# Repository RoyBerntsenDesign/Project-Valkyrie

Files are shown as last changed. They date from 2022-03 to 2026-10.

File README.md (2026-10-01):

# Valkyrie V2


Open-source, open-hardware DIY high-temperature CoreXY FFF platform.

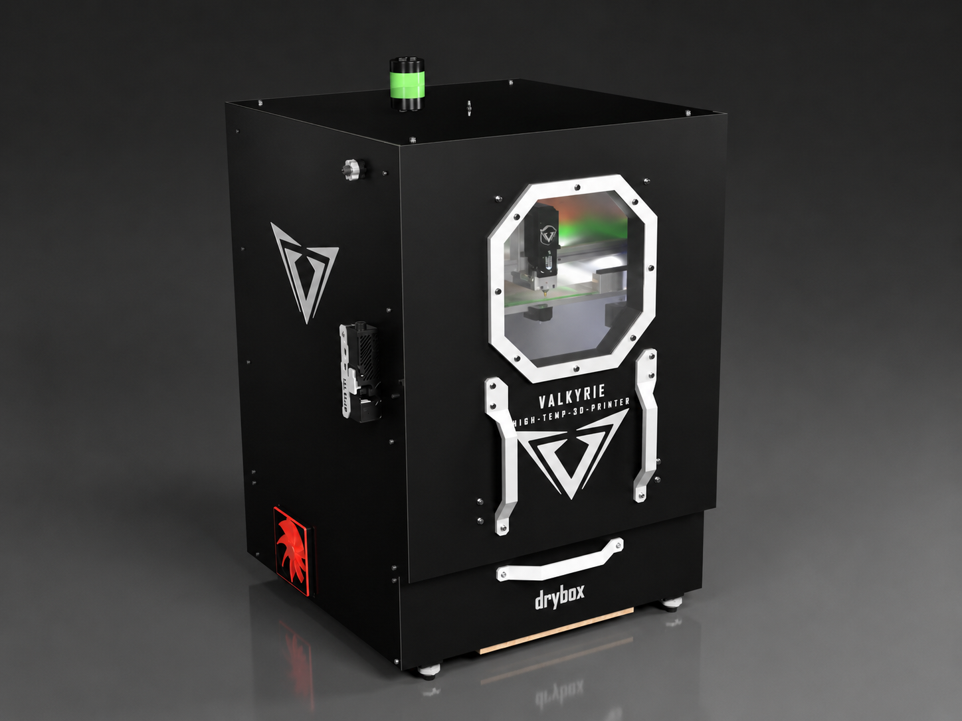
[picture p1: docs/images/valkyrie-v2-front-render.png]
Valkyrie V2 front render


Valkyrie V2 is a complete redesign of the Valkyrie high-temperature printer platform. The design focuses on structural rigidity, high-temperature operation, serviceability, thermal separation, and automated calibration.

The standard electrical configuration is 220-240 VAC. A 110-120 VAC configuration is possible only with configuration-specific heaters, power supplies, switching devices, wiring, connectors, and circuit protection.

## Project status

This repository contains Valkyrie V2.0.0-rc.1, the first release candidate for the Valkyrie V2 platform. Recommended operating values are separated from verified prototype results throughout the documentation. Materials and operating conditions that have not yet been validated are identified accordingly.

## Fusion 360 CAD Model

Explore the complete Valkyrie V2 assembly directly in Autodesk Fusion:

**➡️ [Open the Valkyrie V2 Fusion 360 Model](https://a360.co/4qquDOy)**

The online model includes the latest public design and allows you to inspect the complete assembly and individual components directly in your browser or Fusion 360.

## Main specifications

| System | Specification |
| --- | --- |
| Architecture | CoreXY |
| Build volume | 330 × 300 × 280 mm |
| Bed plate | 350 × 350 × 8 mm cast aluminium 5083 |
| Build sheet | 330 × 330 mm removable build sheet |
| XY motion | External dual-motor CoreXY with all-metal MGN12 linear rails |
| Z motion | Three independently driven belt-lift Z axes |
| XY motors | 2 × NEMA 17, 48 mm, 55 N·cm, 2.5 A, long-shaft |
| Z motors | 3 × NEMA 17, 40 mm, 45 N·cm, 2 A |
| Extruder | BTT V2X, 7:1 gearing, 73.5 N (7.5 kgf) rated extrusion force |
| Hotend | Custom water-cooled Valkyrie high-temperature hotend |
| Maximum nozzle temperature | Up to 500 °C |
| Maximum build-plate temperature | Up to 150 °C |
| Active chamber | Up to 110 °C verified |
| Chamber heater | 750 W PTC heater, configured as RRF Chamber 0 |
| Drybox heater | 300 W PTC heater, configured as RRF Chamber 1 |
| Chamber lighting | 3 × 350 mm, 24 V LED strips |
| Controller | Duet 3 6HC |
| Firmware | RepRapFirmware with Duet Web Control |
| Standard input | 220-240 VAC |
| Optional input | 110-120 VAC with configuration-specific components |

## Recommended and verified performance

| Performance | Recommended | Verified |
| --- | ---: | ---: |
| Print speed | Up to 500 mm/s | 1,000 mm/s |
| Acceleration | Up to 10,000 mm/s² | 10,000 mm/s² |
| Volumetric flow rate | Material-dependent | 45 mm³/s |
| Chamber temperature | Up to 110 °C | 110 °C sustained for 60 min |
| Drybox temperature | Up to 80 °C | 80 °C |
| Maximum travel speed | Up to 500 mm/s | 1,000 mm/s |
| Chamber heat-up | — | 30 min to 100 °C from 25 °C ambient |

Recommended values are intended as practical operating limits for the Valkyrie V2 reference configuration. Actual print settings depend on material, nozzle size, layer height, toolhead configuration, cooling, firmware tuning, and operating temperature.

Verified values represent results demonstrated on the Valkyrie V2 reference machine and should not be interpreted as required operating settings for every build.

## Design overview

### Frame and enclosure

- Aluminium extrusion frame assembled with M6 blind joints.
- Relocated upper rear extrusion for improved chamber sealing, panel installation, cable routing, and service access.
- Additional centre-rear Z extrusion for stiffness and support.
- Vertically lifting overhead door that does not require outward swing clearance.
- Reinforced door brackets with 625ZZ bearings, shoulder bolts, and linked side mechanisms.
- Primary electronics, motors, radiator, pump, and part-cooling blower positioned outside the heated chamber where practical.

### Motion system

- External 2.5 A CoreXY motors with long shafts and upper shaft supports.
- 16T GT2 drive pulleys for increased torque and nominal motion resolution.
- F606ZZ flanged CoreXY idlers.
- High-temperature all-metal MGN12 linear rails.
- Three independent belt-driven Z axes with 5:1 reduction and automatic Z alignment.

### Build platform and calibration

- Cast aluminium 5083 bed plate.
- Three-point Maxwell kinematic mounting system using 10 mm bearing balls.
- Integrated SmCo magnets and locating pins for repeatable build-sheet positioning.
- Bed-mounted nozzle and Z-offset reference sensor.
- Automatic three-point Z alignment, mesh-bed compensation, nozzle-height measurement, and nozzle brushing.

### Toolhead and thermal management

- Water-cooled BTT V2X extruder motor and custom Valkyrie hotend.
- Closed-loop cooling system using a P67D pump, reservoir, and external 120 mm radiator.
- 750 W PTC chamber heater with a 120 CFM recirculation fan.
- Heated bed provides a secondary chamber heat source.
- Independent thermal switch and firmware-configured heater protection.
- External ROBO blower recirculates heated chamber air for part cooling through a CPAP hose and toolhead duct.

### Material management

- Integrated heated filament drybox operating up to 80 °C.
- RepRapFirmware controls the drybox heater as Chamber 1.
- ESP32 monitoring of the DHT22 temperature/humidity sensor and filament load cell.
- Desiccant container and 625ZZ-bearing filament carousel.
- External filament buffer supporting automatic filament loading and unloading.

### Electronics and firmware

- Duet 3 6HC using all six onboard stepper-driver channels.
- Primary 24 V, 350 W power supply and secondary 12 V power supply.
- TS35 DIN-rail mains and 12 V distribution.
- Three solid-state relays for the bed, chamber, and drybox heaters.
- Three 350 mm, 24 V chamber LED strips: two vertical front strips pointing toward the rear and one top-front strip pointing toward the toolhead/build area.
- RepRapFirmware and Duet Web Control.
- Input shaping, pressure advance, automatic Z alignment, mesh compensation, thermal monitoring, and configurable print-start and print-end sequences.

## Firmware

Valkyrie V2 uses RepRapFirmware and Duet Web Control on the Duet 3 6HC.

The tested Valkyrie V2 firmware configuration is included in this repository:

[Open Valkyrie V2 Firmware Files](Firmware%20Files)

The supplied firmware package contains:

- `sys` – RepRapFirmware configuration, homing, system and safety files
- `macros` – Valkyrie-specific probing, calibration, nozzle and utility macros
- `filaments` – material-specific filament configuration, load and unload files

These files are configured for the Valkyrie V2 reference machine and should be used as the basis for the printer firmware setup.

### Firmware upgrades

For RepRapFirmware and Duet firmware upgrade procedures, follow the Valkyrie firmware upgrade guide:

[Valkyrie Firmware Upgrade Guide](https://docs.google.com/document/d/1ZG3JhbeEWcIs_WRdMjnoR0Aa20OJ4TtpdeJnv2xmSmU/edit?usp=sharing)

Back up the SD card before making firmware or configuration changes.

Machine-specific settings such as input shaping, probe offsets and filament profiles may require adjustment on individual builds.

## Material validation

Validated on the current prototype:

- PLA
- PETG
- ABS
- ASA
- PA and PA-CF
- PC, PC-CF, and PC blend CF
- PPS, PPS-CF, and PPS-GF

Still to be verified:

- PSU
- PPSU
- PEI (Ultem)
- PEKK

## Documentation

- [Valkyrie V2 Technical Overview v1.1](docs/Valkyrie_V2_Technical_Overview_v1.1.pdf)
- [Valkyrie V2.0.0-rc.1 release notes](RELEASE_NOTES.md)

The technical overview describes the machine architecture and prototype configuration. It is not an assembly manual or electrical wiring guide.

## Support

For build assistance, troubleshooting, and questions about Valkyrie V2, please join the official Project Valkyrie Discord server:

[**Get support on Discord**](https://discord.gg/mWARcpt7NQ)

## Safety

Valkyrie V2 uses mains-voltage heaters, high current, high temperatures, moving machinery, and liquid cooling. Mains-voltage components, wiring, connectors, protective earth, fusing, insulation, and clearances must be selected and installed for the configured input voltage by a qualified person in accordance with applicable regulations and manufacturer ratings.

Do not use the project documentation as a substitute for electrical design verification, risk assessment, or compliance testing.

## Credits

### Project lead

**Roy Berntsen** - Project lead, primary mechanical designer, and system integrator.

### Contributors

- **Mark Bridgewater** - Design, electronics, firmware, testing, and documentation.
- **Chris Lombardi** - ESP32 firmware.

### Acknowledgements

- RepRapFirmware
- Duet Web Control
- Duet3D
- BIQU

## Licensing

Beginning with V2.0.0-rc.1, Valkyrie V2 is released as an open-source and open-hardware project.

- Hardware design files: **CERN-OHL-S-2.0**
- Valkyrie firmware, macros, and configuration: **GPL-3.0-or-later**
- Documentation and original project media: **CC-BY-4.0**

Earlier tagged releases remain under the licence terms under which they were originally published. Third-party materials remain subject to their respective licences.

See [License.md](License.md) and the full licence texts in [LICENSES](LICENSES).

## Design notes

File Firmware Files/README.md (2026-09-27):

# Valkyrie V2 – RepRapFirmware Files

These files contain the Valkyrie V2 RepRapFirmware configuration used on the reference machine.

The supplied `sys`, `macros` and `filaments` folders should be used as the basis for the Valkyrie V2 firmware setup.

## Included folders

- `sys`  
  Main RepRapFirmware configuration files, homing files, daemon logic, pause/resume, stop/cancel and other system files.

- `macros`  
  Valkyrie-specific macros for probing, nozzle handling, Z-offset calibration, chamber control and other printer functions.

- `filaments`  
  Material-specific filament configuration, load and unload files.

## Installation

1. Back up the existing SD card before making any changes.
2. Download the Valkyrie V2 firmware files from this repository.
3. Copy the supplied `sys`, `macros` and `filaments` folders to the Duet SD card.
4. Follow the Valkyrie firmware upgrade guide when updating RepRapFirmware or Duet firmware.
5. Restart the controller.
6. Verify the machine configuration before enabling heaters or motion.

## Firmware Upgrade Guide

For RepRapFirmware and Duet firmware upgrade procedures, use the Valkyrie firmware upgrade documentation:

[Valkyrie Firmware Upgrade Guide](https://docs.google.com/document/d/1ZG3JhbeEWcIs_WRdMjnoR0Aa20OJ4TtpdeJnv2xmSmU/edit?usp=sharing)

## Important

These files are configured specifically for the Valkyrie V2 hardware.

Before operating the machine, verify:

- motor directions
- axis limits
- sensorless homing behaviour
- heater and thermistor assignments
- fan assignments
- probe inputs
- Z-probe offsets
- mains-powered heater control
- chamber safety systems

## Input Shaping

The included input-shaping configuration was measured on the Valkyrie V2 reference machine.

Another build may have different resonance characteristics due to differences in:

- frame assembly
- belt tension
- toolhead mass
- component tolerances
- mounting
- modifications

Input shaping should therefore be measured and tuned on each machine where possible.

## Filament Profiles

The supplied filament profiles are based on the materials and settings used on the Valkyrie V2 reference machine.

Temperatures, purge lengths, drybox temperatures and other material-specific settings may need adjustment for different filament brands and formulations.

## Safety

Valkyrie is a DIY high-temperature 3D printer and includes mains-voltage heaters.

Make sure all wiring, grounding, fusing, thermal protection and heater configuration are checked before operating the machine.

Do not rely on firmware as the only safety system.

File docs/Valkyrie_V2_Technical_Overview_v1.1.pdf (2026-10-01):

# Valkyrie V2 Technical Overview

## Open-Source / Open-Hardware DIY High-Temperature CoreXY Platform

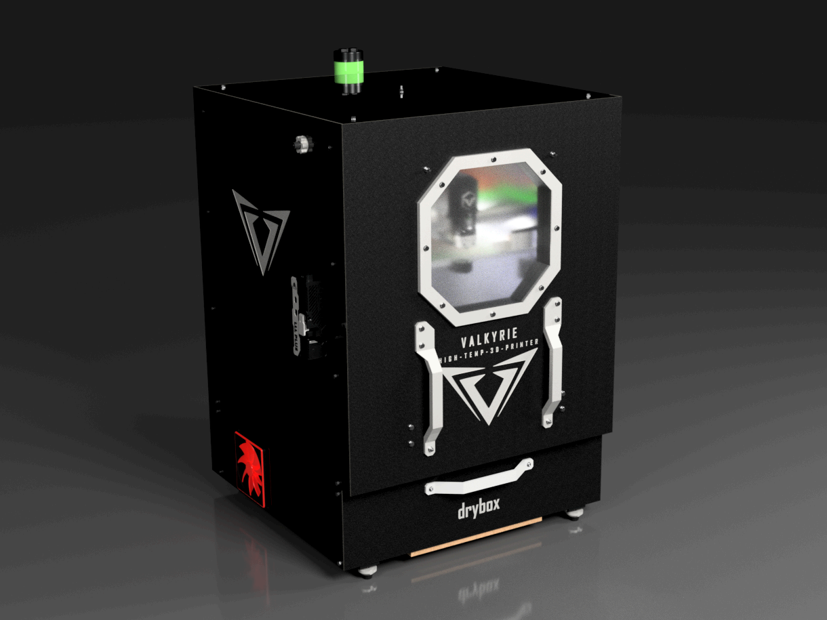
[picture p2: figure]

Designed and developed by Roy Berntsen Document version 1.1
October 2026

## Table of Contents INTRODUCTION

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
cific

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
cific

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
rial C

o

m

p

a

tibilit

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
alib

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
olin

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
olin

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
Fila

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
ol | 1
| 3
Fila

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
m | 1
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
ol | 1
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
ol | 1
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
m | 1
| 5
M

ain

s In

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
n | 1
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
al In

t

e

rf

a

c

e | 1
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
olin

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
g | 1
| 6
E

x

t

e

r

n

al Ele

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
N | 1
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
r In

t

e

rf

a

c

e | 1
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
ol | 1
| 7
T

h

e

r

m

al M

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
t | 1
| 7
C

alib

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
s | 1
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
g | 1
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
d | 1
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
s | 1
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
## INTRODUCTION

The Valkyrie V2 is a next-generation, open-source and open-hardware DIY high-temperature CoreXY FFF platform engineered for reliable processing of advanced engineering polymers and fibre-reinforced composites. Every major subsystem has been redesigned to increase structural rigidity, improve motion precision, enhance thermal capability, and simplify servicing while maintaining an open and modular architecture.

This document provides a technical overview of the major design changes and new features introduced in the Valkyrie V2 platform.

Safety Notice
This document is a technical overview, not a wiring or construction guide. Mains-voltage components, wiring, connectors, protective earth, fusing, insulation, and clearances must be selected and installed for the configured input voltage by a qualified person in accordance with applicable regulations and manufacturer ratings.

## SPECIFICATIONS

System Specifications

Specification | Valkyrie V2
Printer Architecture | CoreXY
Build Volume | 330 × 300 × 280 mm
Frame Construction | Aluminium extrusion frame
XY Motion System | CoreXY with external NEMA 17 stepper motors
XY Motors | 2 × NEMA 17, 48 mm, 55 N·cm, 2.5 A, long-shaft
Z Motion System | Three independently driven belt-lift Z axes
Z Motors | 3 × NEMA 17, 40 mm, 45 N·cm, 2 A
XY Positioning Resolution | 10 µm/step
Z Positioning Resolution | 2.5 µm/step
Linear Rails | High-temperature all-metal MGN12
Extruder | BTT V2X, 7:1 gearing
Extrusion Force | 73.5 N (7.5 kgf)
Hotend | Custom water-cooled Valkyrie hotend
Maximum Nozzle Temperature | Up to 500 °C

Maximum Build Plate Temperature | Up to 150 °C
Active Chamber Temperature | Up to 110 °C verified
Chamber Heating | 750 W PTC heater (RRF Chamber 0)
Chamber Lighting | 3 × 350 mm, 24 V LED strips
Bed Plate | 350 × 350 × 8 mm Cast Aluminium Al 5083
Bed Mounting | 3-point Maxwell kinematic system with 10 mm bearing balls
Build Plate Retention | Integrated SmCo magnets
Calibration | Automatic tool probe, Z sensor, mesh bed levelling
Part Cooling | Recirculated chamber-air CPAP system
Toolhead Cooling | Closed-loop water cooling
Water Cooling | 12 V P67D pump, reservoir, and 120 mm radiator
Filament Storage | Integrated heated drybox
Drybox Heating | 300 W PTC heater (RRF Chamber 1)
Drybox Control | RRF Chamber 1 heater control with ESP32/DHT22 monitoring
Filament Monitoring | Integrated load cell with remaining filament weight
Filament Feeding | External filament buffer
Control Electronics | Duet 3 6HC
Firmware | RepRapFirmware
User Interface | Duet Web Control (DWC)
Standard Input Voltage | 220–240 VAC
Optional Input Voltage | 110–120 VAC with configuration-specific electrical components
Mains Protection | 10 A fuse for the standard 220–240 VAC configuration
Machine Weight | ~50 kg

The Valkyrie V2 is designed around a standard 220–240 VAC electrical configuration. An optional 110–120 VAC configuration may be built using appropriately rated heaters, power supplies, switching devices, wiring, connectors, and circuit protection

Performance Specifications

Performance | Recommended | Verified
Print Speed | Up to 500 mm/s | 1,000 mm/s
Acceleration | Up to 10,000 mm/s² | 10,000 mm/s²
Volumetric Flow Rate | Material-dependent | 45 mm³/s
Maximum Travel Speed | Up to 500 mm/s | 1,000 mm/s
Chamber Heat-Up Time | — | 30 min to 100 °C (from 25 °C ambient)
Chamber Temperature | Up to 110 °C | 110 °C for 60 min
Drybox Temperature Range | Up to 80 °C | 80 °C

Material Compatibility

Material | Status
PLA | ✓
PETG | ✓
ABS | ✓
ASA | ✓
PA/PA-CF | ✓
PC/PC-CF/PC Blend CF | ✓
PPS/PPS-CF/GF | ✓
PSU | To be verified
PPSU | To be verified
PEI (Ultem) | To be verified
PEKK | To be verified

✓ = Verified on the current prototype. “To be verified” indicates materials that have not yet been validated The Valkyrie V2 is designed to process engineering-grade thermoplastics and fibre-reinforced composites.

## 1.MACHINE PLATFORM

FRAME

- Increased frame rigidity with M6 blind joints while simplifying the assembly process
- Improved chamber sealing and cable routing by relocating the upper rear 2020 X profile
- Added a center rear 2020 Z extrusion to improve structural stiffness and support
- Redesigned the top frame structure to enable top-mounted linear rails for easier installation and servicing

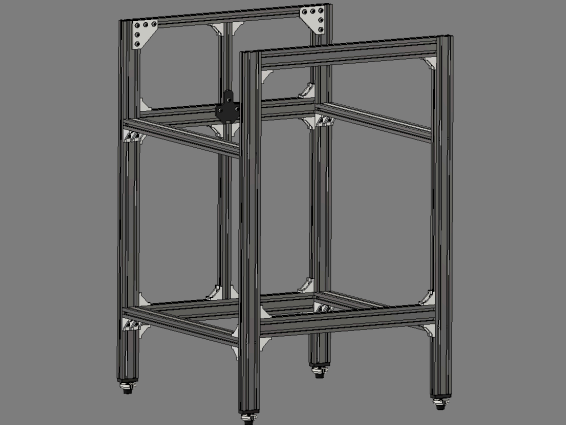
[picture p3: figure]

Figure 1 — Valkyrie V2 frame.

ENCLOSURE

- Redesigned enclosure architecture for improved chamber sealing and reduced heat loss during high-temperature operation
- Relocated upper rear 2020 X profile to simplify panel installation, improve sealing, and provide cleaner cable routing
- Improved separation between the heated build chamber and temperature-sensitive electronics and cooling components
- Service-oriented panel arrangement providing access to motion, wiring, and thermal-management components
- External mounting of the CoreXY motors, Z motors, water-cooling radiator, pump, and part cooling blower fan to reduce exposure to elevated chamber temperatures
- Integrated routing interfaces for toolhead wiring, water-cooling hoses, CPAP ducting, and filament feeding
- Redesigned overhead-lifting door system that opens vertically instead of swinging outward, reducing the required clearance in front of the machine
- Upgraded door hinge and linkage system featuring:
- New reinforced mounting brackets
- 625ZZ bearings and shoulder bolts at the arm and bracket pivot points for smoother movement and reduced play
- Improved mechanical linkage between both sides for synchronized door movement and more consistent alignment
(a) Closed door | (b) Open door

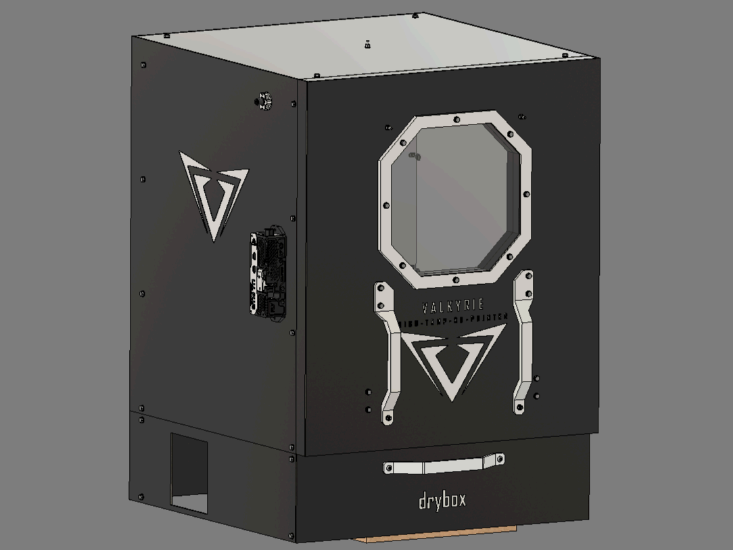
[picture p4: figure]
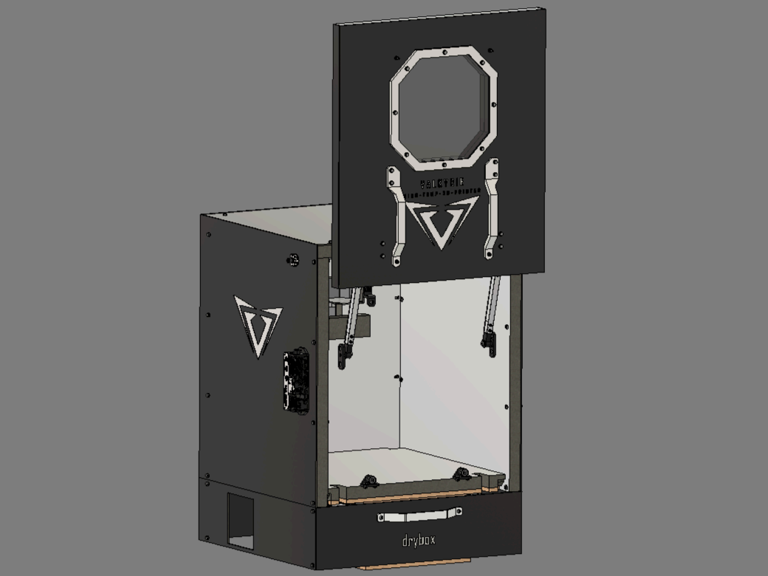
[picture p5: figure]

Figure 2 - Valkyrie V2 overhead door in the closed and fully raised positions. The vertically lifting mechanism provides unobstructed access to the build chamber without requiring additional clearance in front of the machine.

## 2.MOTION SYSTEM

CoreXY Motion System

- New external 2.5 A NEMA 17 long-shaft stepper motors with top-supported shafts for improved drive stiffness:
- Reduced shaft deflection for improved motion consistency and repeatability
- Improved pulley alignment and belt stability
- Increased belt tension capability for a stiffer CoreXY drive system
- Increased acceleration capability and torque margin
- Improved reliability during high-temperature operation
- Reduced CoreXY drive pulleys from 20T to 16T GT2 for increased positioning resolution at 10 µm/step and higher torque
- Upgraded all GT2 idlers to large diameter F606ZZ flanged bearings for reduced friction, improved belt guidance, less belt stress, and increased long-term reliability
- Upgraded AB motion system to all-metal high-temperature MGN12 linear rails for improved rigidity and reliability in elevated chamber temperatures
- Redesigned AB and Y motion components for improved rigidity, belt alignment, and serviceability

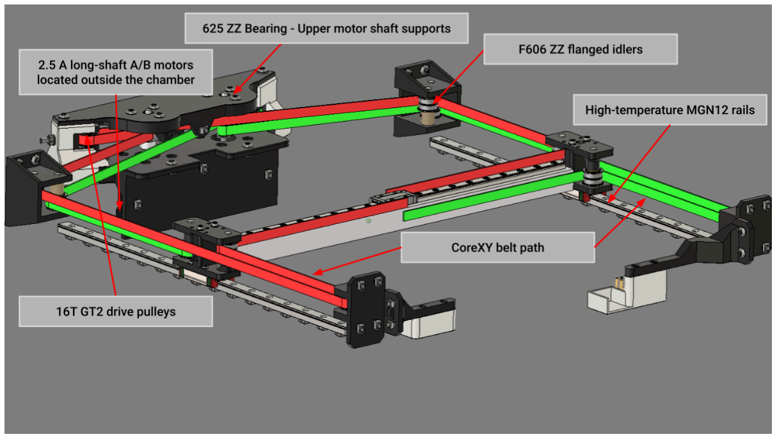
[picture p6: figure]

Figure 3 — Valkyrie V2 CoreXY motion system showing the external long-shaft A/B motors, upper shaft supports, 16T drive pulleys, F606ZZ idlers, and high-temperature MGN12 linear rails.

Z Motion System

- Redesigned Z carriers for increased rigidity, improved belt clamping, and ease of servicing
- New top-mounted Z idler brackets for maximum toolhead travel and optimized belt routing
- Increased Z drive reduction from 4:1 to 5:1 using 16T GT2 pulleys for higher positioning resolution at 2.5 µm/step and increased torque
- Upgraded Z belt idlers to GT2 pulleys on 625ZZ bearing shafts for improved belt guidance and reduced friction
- High-temperature all-metal MGN12 linear rails for improved reliability in elevated chamber temperatures

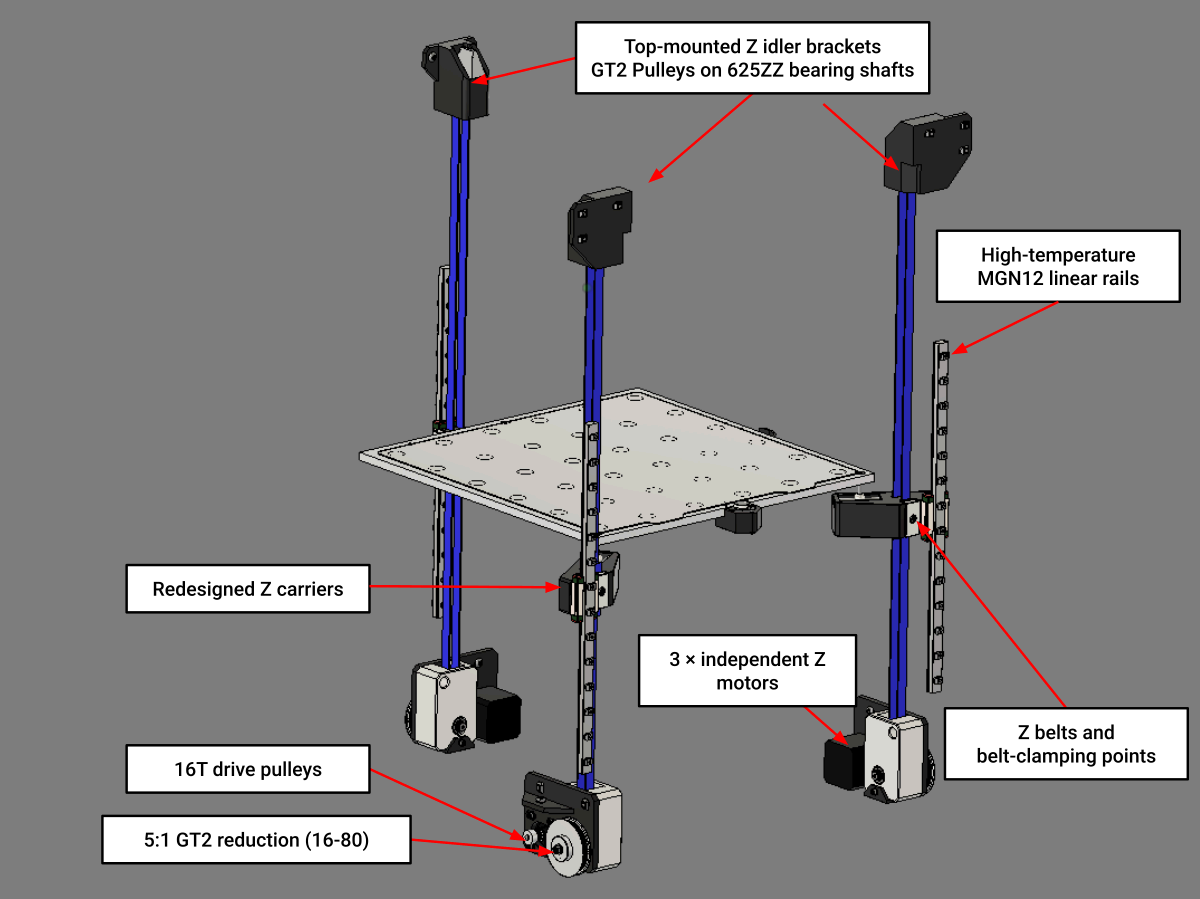
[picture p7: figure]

Figure 4 — Three-axis Z motion system featuring independent NEMA 17 motors, 5:1 GT2 reduction, top-mounted idlers, redesigned Z carriers, and high-temperature MGN12 linear rails.

## 3.BUILD PLATFORM

Bed System

- Integrated SmCo magnets for secure build plate retention and improved high-temperature stability
- Redesigned bed wiring with improved strain relief and integrated thermal fuse for increased electrical safety
- Added locating pins for repeatable build plate positioning and alignment
- 3-point independent Maxwell kinematic bed system using 10 mm bearing balls for high stability and repeatable bed positioning

Calibration System

- New Valkyrie tool probe system for automatic Z-offset measurement and nozzle height calibration
- Bed-mounted nozzle/Z-offset sensor provides a fixed reference for automatic nozzle-height measurement and Z-offset calibration
- Improved calibration repeatability for consistent first-layer performance

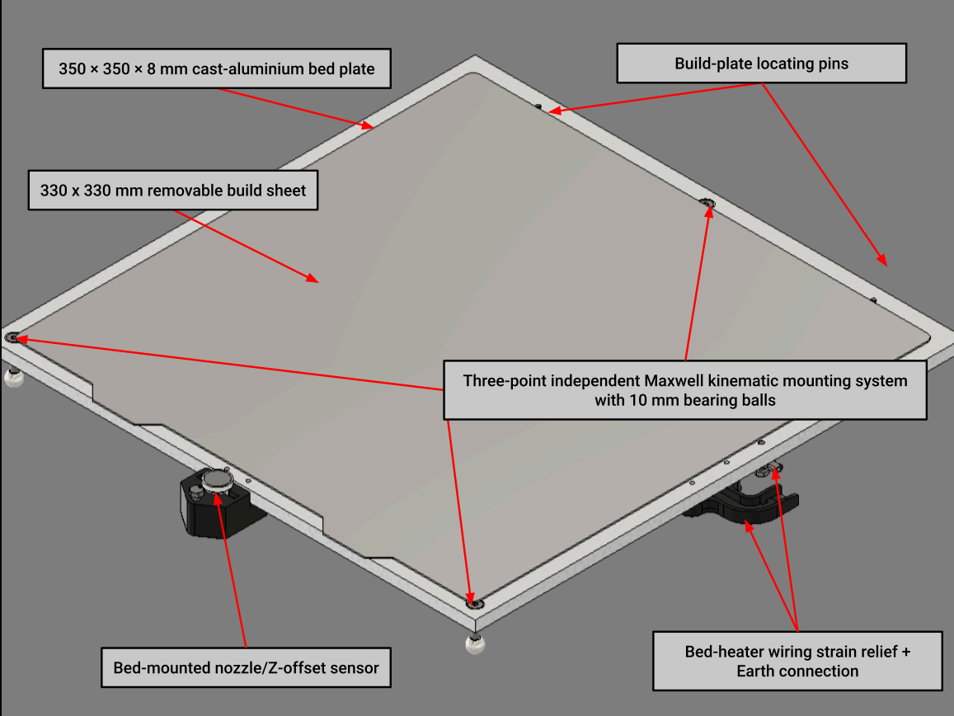
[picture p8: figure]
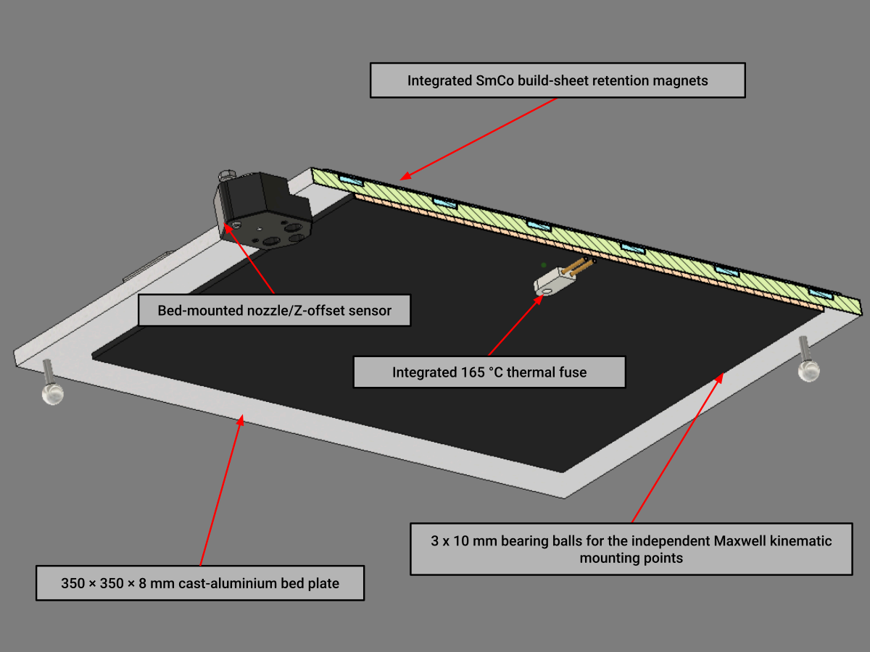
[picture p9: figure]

(a) Top view | (b) Underside view

Figure 5 — Valkyrie V2 build platform: (a) 330 × 330 mm removable build sheet, cast-aluminium bed plate, SmCo magnetic retention, locating pins, and bed-mounted nozzle/Z-offset sensor; (b) three-point Maxwell kinematic mounting system, heater wiring, strain relief, and thermal fuse.

## 4.TOOLHEAD PLATFORM

- New water-cooled BTT V2X high-torque extruder featuring 7:1 gearing and 73.5 N (7.5 kgf) extrusion force for reliable high-force extrusion and high-flow material processing
- Custom water-cooled high-temperature hotend developed specifically for the Valkyrie V2 toolhead, featuring an integrated toolplate mounting interface for improved rigidity, alignment, and serviceability
- Redesigned integrated toolhead cable management featuring:
- Top-mounted cable chimney routing through the toolhead cover
- Integrated side cable channel for cleaner cable routing and improved protection
- Redesigned Z probe system with SmCo magnets for improved thermal stability and repeatability
- New magnetic Z probe docking station with SmCo magnets for secure probe retention and consistent positioning
- New nozzle brushing station for improved nozzle maintenance and print reliability

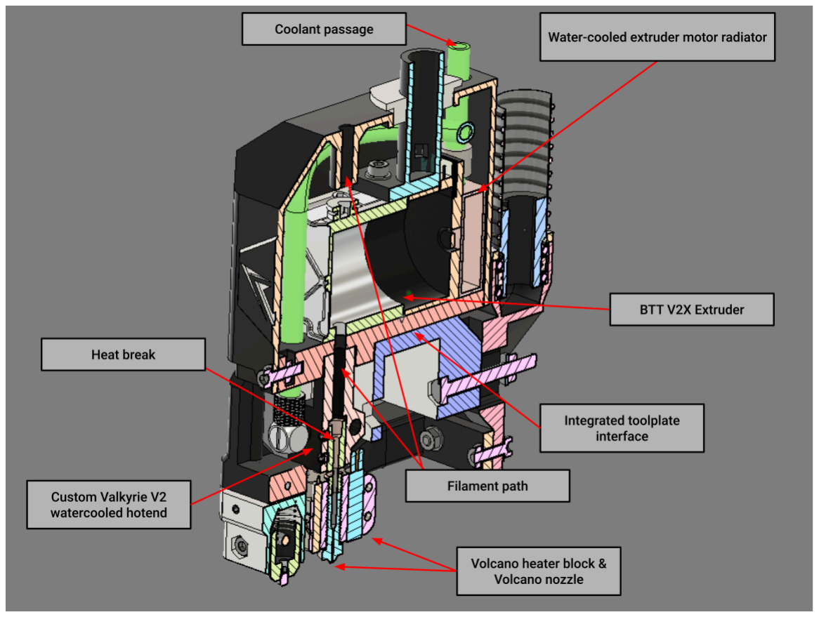
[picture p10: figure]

Figure 6 — Section view of the Valkyrie V2 toolhead showing the filament path, extruder drive, integrated mounting interface, and water-cooled high-temperature hotend assembly.

## 5.THERMAL MANAGEMENT

Water Cooling System

- Closed-loop water-cooling system using a 12 V P67D pump with water reservoir
- Dedicated cooling circuit for the extruder motor and hotend
- Integrated reservoir with fill and bleed ports for simplified coolant filling and air removal
- 120 mm radiator mounted outside the heated chamber for efficient heat rejection
- PWM-controlled radiator fan
- Cooling system isolated from the heated chamber environment

Chamber Heating System

- Dedicated 220 V, 750 W PTC chamber heater positioned centrally at the rear of the build chamber
- 220 V, 750 W heated bed provides an additional secondary heat source during chamber heating
- High-flow 120 CFM, 12 V, 92 × 92 × 38 mm circulation fan distributes heated air throughout the chamber
- Fully recirculated airflow maintains a uniform chamber temperature without introducing cooler external air
- Temperature sensor positioned at nozzle level for representative chamber-temperature measurement
- Controlled chamber operation verified up to 110 °C for processing high-temperature engineering polymers; sustained operation verified at 110 °C for 60 min
- Integrated thermal switch provides independent hardware over-temperature protection
- Firmware-configured temperature limits and automatic heater shutoff provide additional thermal safety

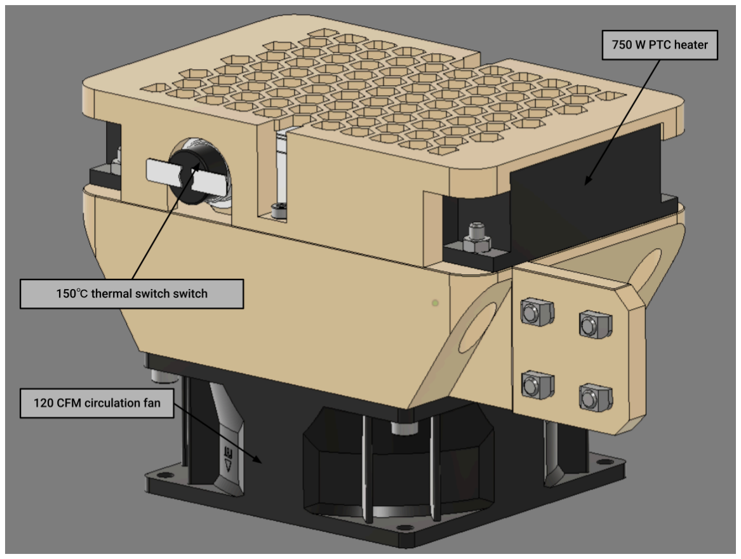
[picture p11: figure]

Figure 7 — Chamber-heating assembly showing the 750 W PTC heater, 120 CFM chamber-circulation fan, and independent 150 °C thermal safety switch.

Part Cooling System

- High-flow part-cooling system using an external 12 V ROBO CPAP fan
- Recirculates heated chamber air instead of introducing cooler external air, minimizing thermal shock during high-temperature printing
- Directs controlled airflow through the toolhead chimney and duct system onto the printed part
- Improves overhang and bridging performance when processing high-temperature engineering polymers
- Bearing-supported CPAP hose swivel allows free hose rotation and reduces mechanical load on the moving toolhead
- Adjustable fan control enables part-cooling airflow to be matched to the material and printing conditions

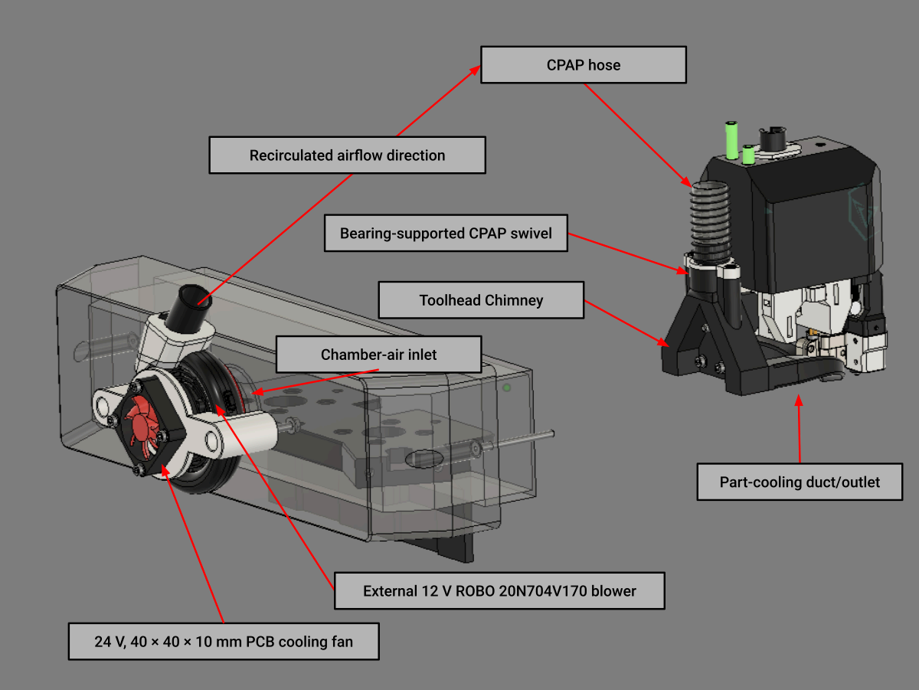
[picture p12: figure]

Figure 8 — Valkyrie V2 recirculated-air part-cooling system showing the chamber-air inlet, external ROBO blower, dedicated control-PCB cooling fan, CPAP hose, bearing-supported swivel, and toolhead duct directing heated chamber air onto the printed part.

## 6.MATERIAL MANAGEMENT

Filament Drybox

- Integrated enclosed filament drybox for moisture-sensitive engineering materials
- Dedicated 300 W PTC heater with independent temperature control
- Integrated desiccant container for passive moisture absorption and low-humidity filament storage
- Integrated humidity sensor for continuous drybox monitoring
- Integrated load cell for continuous filament-weight measurement
- Bearing-supported filament carousel using 625ZZ bearings for low-friction rotation and reliable filament feeding
- Drybox operating temperature up to 80 °C

Drybox Monitoring and Control

- RepRapFirmware directly controls the 300 W drybox PTC heater through a dedicated solid-state relay
- The drybox heater is configured in Duet Web Control as Chamber 1
- Drybox temperature setpoint, heater status, and temperature regulation are managed through DWC
- ESP32 monitoring reads the DHT22 temperature/humidity sensor and load cell
- The load cell provides continuous measurement of remaining filament weight
- The ESP32 operates as a monitoring system and does not switch or regulate the drybox PTC heater

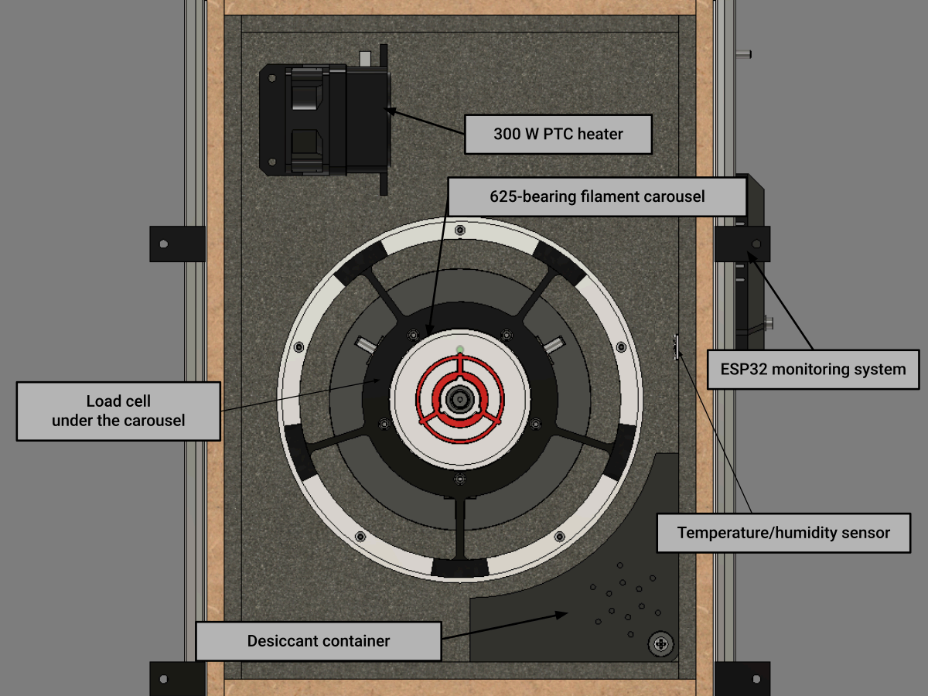
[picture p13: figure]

Figure 9 — Integrated filament drybox showing the heated and monitored storage system, desiccant container, load cell, and bearing-supported filament carousel

Filament Feed System

- External filament buffer positioned between the drybox and toolhead
- Isolates the extruder from spool inertia and drybox feed resistance
- Maintains consistent filament delivery during high-speed printing
- Supports automatic filament loading and unloading directly through the buffer
- Provides controlled filament storage and movement during loading, printing, and unloading operations

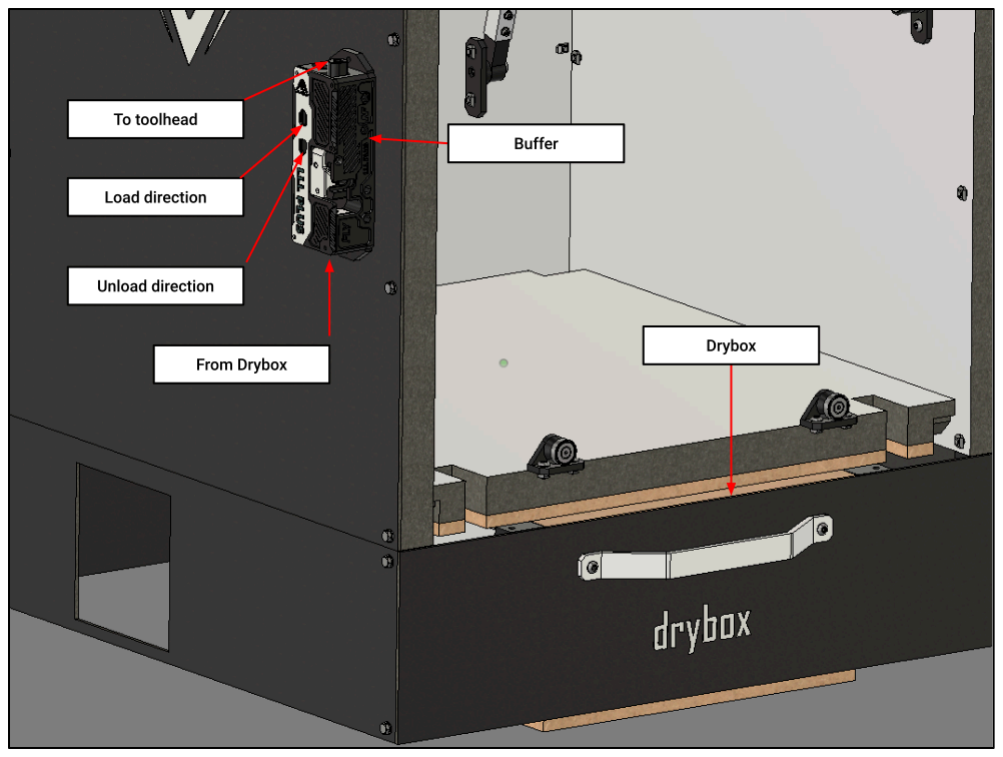
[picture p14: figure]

Figure 10 — External filament buffer providing automatic filament loading and unloading while isolating the toolhead extruder from spool inertia and drybox feed resistance.

## 7. ELECTRONICS & CONTROL SYSTEM

Main Control

- Duet 3 6HC main controller with six integrated stepper-driver channels
- No Duet expansion boards or CAN-connected toolhead electronics
- Controller mounted on the rear panel outside the heated build chamber for improved thermal reliability and service access
- All primary control and power-distribution electronics are located outside the heated chamber
- GX20 panel connectors positioned immediately outside the chamber provide the toolhead electrical interface

Motor Control

- Two independently driven CoreXY A/B motors:
- NEMA 17
- 48 mm body length
- 55 N·cm holding torque
- 2.5 A rated current
- Long shafts with upper support
- Three independently driven Z motors:
- NEMA 17
- 40 mm body length
- 45 N·cm holding torque
- 2 A rated current
- One driver channel controls the BTT V2X extruder motor
- Independent control of the three Z motors enables automatic build-platform alignment
- All six onboard Duet 3 6HC stepper-driver channels are utilized

Power System

- Primary 24 V, 350 W power supply for the controller, motion system, chamber lighting, and other 24 V components
- Secondary 12 V power supply for pumps, fans, and auxiliary 12 V components
- TS35 DIN-rail-mounted mains and 12 V distribution for organized and serviceable wiring
- Three solid-state relays with 24 V DC control inputs switch the following 220 V AC heating loads:
- 750 W build-plate heater
- 750 W chamber PTC heater
- 300 W drybox PTC heater

Mains Input and Protection

- Main IEC connector provides the external AC power connection
- Dedicated main power switch
- 15 A panel-mounted fuse holder fitted with a 10 A mains fuse

Chamber Electrical Interface

- High-temperature HDC connectors provide centralized, serviceable connections between the electronics system and heated chamber
- One 6-pin HDC connector supplies the 750 W chamber PTC heater
- One 6-pin HDC connector supplies the 4-pin 120 CFM chamber circulation fan
- One 10-pin HDC connector carries connections for:
- Build-plate heater
- Bed thermistor
- Z-offset/nozzle sensor
- Protective earth
- Centralized chamber connectors simplify installation, servicing, and component replacement

Electronics and Component Cooling

- 12 V, 120 × 120 × 25 mm fan for the water-cooling radiator
- 12 V ROBO 20N704V170 blower for recirculated-air part cooling
- 12 V, 60 × 60 × 25 mm fan for drybox-heater air circulation
- 12 V, 92 × 92 × 38 mm, 120 CFM fan for chamber-heater air circulation
- 24 V, 40 × 40 × 10 mm fan for Duet 3 6HC cooling
- 24 V, 40 × 40 × 10 mm fan for ROBO-fan control-PCB cooling

Chamber Lighting

- Three internal 24 V LED strips, each 350 mm long, provide illumination of the build chamber
- Two vertically mounted LED strips are installed on the front Z profiles and directed toward the rear of the chamber
- One LED strip is mounted at the top front of the chamber and directed toward the toolhead and build area
- Combined front and overhead illumination improves visibility of the toolhead, printed part, and internal chamber components

External Electronics Architecture

- Active electronics are positioned outside the heated build chamber wherever possible. The water-cooled toolhead extruder motor and the chamber circulation fan are the only active electromechanical components operating inside the chamber.
- External component placement reduces thermal exposure and improves reliability, accessibility, and serviceability

## 8. FIRMWARE & AUTOMATION

Firmware and User Interface

- RepRapFirmware (RRF) provides motion control, thermal management, calibration, safety monitoring, and printer automation
- Duet Web Control (DWC) provides the primary browser-based interface for printer operation, monitoring, file management, and configuration
- Printer configuration files and macros are stored locally on the Duet 3 6HC controller

Motion Control

- Input shaping reduces vibration and motion-related surface artifacts
- Pressure advance compensates for extrusion-system pressure changes during acceleration and deceleration
- Automated axis-homing routines establish repeatable machine coordinates
- Independent control of three Z motors enables automatic build-platform alignment
- Configurable speed, acceleration, current, and motion limits for each axis

Thermal Management

- Closed-loop temperature regulation for the hotend, build plate, and heated chamber
- RepRapFirmware independently regulates the drybox PTC heater as Chamber 1, with its temperature setpoint and operating status accessible through Duet Web Control
- Print start heats the chamber and bed first, waits for the configured minimum chamber temperature, then heats the hotend to reduce unnecessary high-temperature dwell
- Chamber, drybox, and water-pump tachometer monitoring supplements heater limits and sensor-fault handling; confirmed cooling faults trigger automatic heater shutdown
- Temperature-sensor faults automatically disable the affected heater

Calibration

- Automatic three-point Z alignment using the independently driven Z motors
- Automatic mesh bed levelling compensates for build-surface variation
- Valkyrie tool-probe system measures nozzle height and Z offset
- Automated nozzle-probing sequence provides repeatable first-layer calibration
- Nozzle-brushing routine cleans the nozzle before probing and printing

Safety

- Thermal-runaway and cooling-system monitoring for firmware-controlled heaters
- Configurable minimum- and maximum-temperature limits
- Automatic heater shutdown following sensor faults, heating errors, exceeded limits, or confirmed fan/pump cooling faults
- Independent thermal switches provide hardware-level over-temperature protection
- Build-plate heater wiring includes an integrated thermal fuse
- Mains fuse protects the printer’s primary electrical input

Automation Features

- Automated machine homing and three-point bed alignment
- Automatic Z-offset measurement and mesh-bed calibration
- Automatic nozzle-brushing sequence
- Automated filament loading and unloading through the external filament buffer
- Print-start sequence heats the chamber and bed first, waits for the configured minimum chamber temperature, then heats the hotend before homing and calibration
- Configurable print-end sequence for heater shutdown, toolhead parking, and filament management

## Credits and Licensing

Project Lead

Roy Berntsen
Project lead, primary mechanical designer and system integrator

Contributors

- Mark Bridgewater — Design, electronics, firmware, testing and documentation
- Chris Lombardi — ESP32 firmware

Acknowledgements
- RepRapFirmware and Duet Web Control
- Duet3D and BIQU

Licensing

Beginning with Valkyrie V2.0.0-rc.1, Project Valkyrie is released as an open-source and open-hardware project. Hardware design files are licensed under CERN-OHL-S-2.0, original Valkyrie firmware and configuration under GPL-3.0-or-later, and original documentation and project media under CC-BY-4.0. Earlier tagged releases remain under their original licence terms. Third-party materials remain subject to their respective licences.

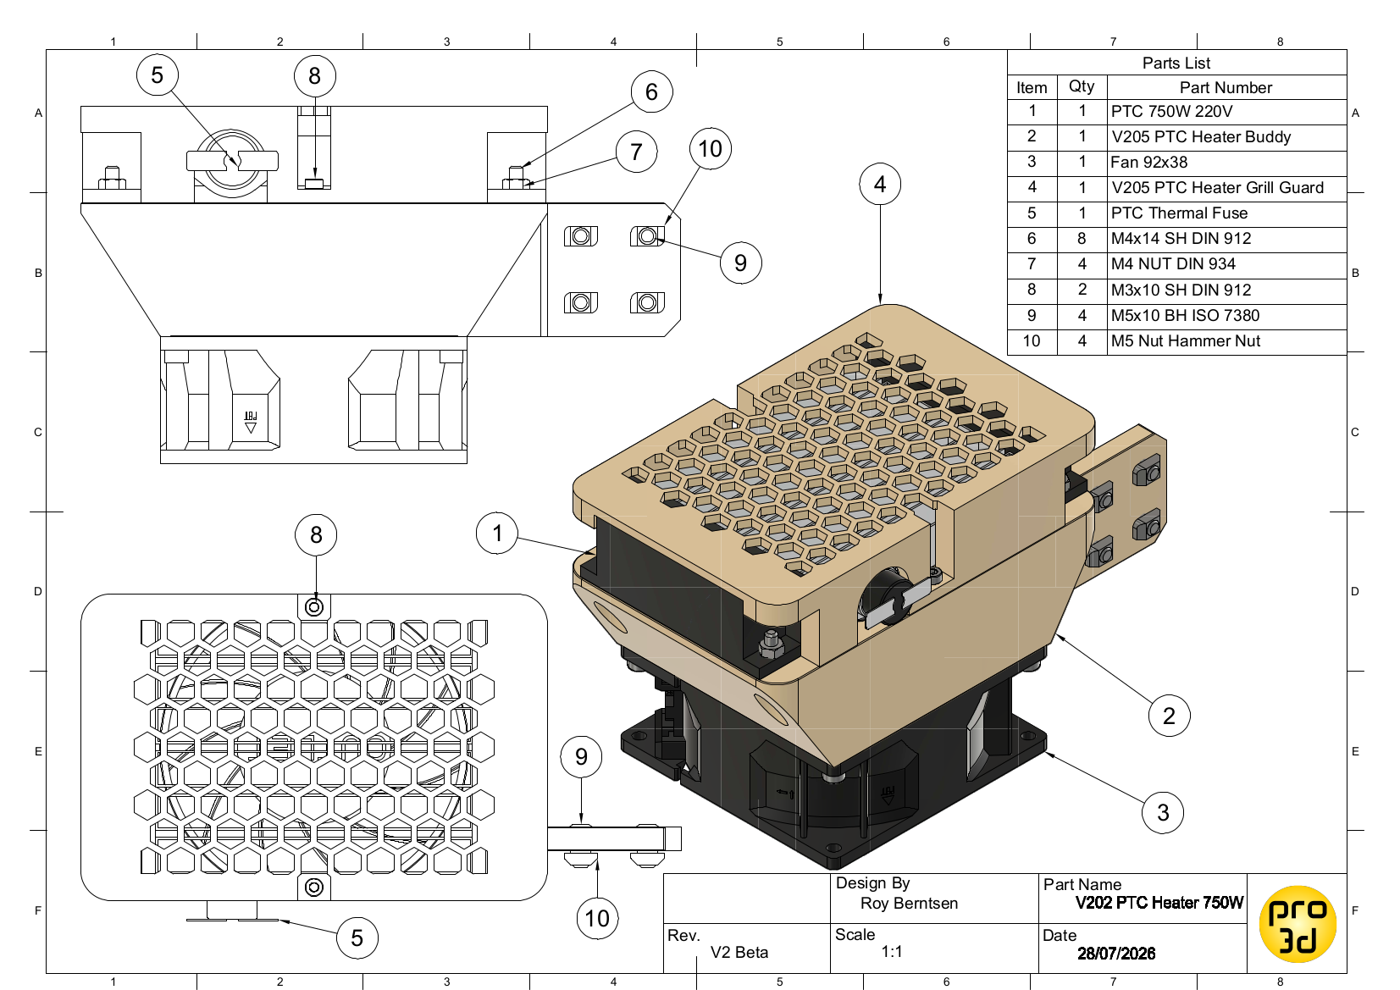
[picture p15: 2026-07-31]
Drawings/4 Electronic Drawings/V212 PTC Heater 750W Drawing.png

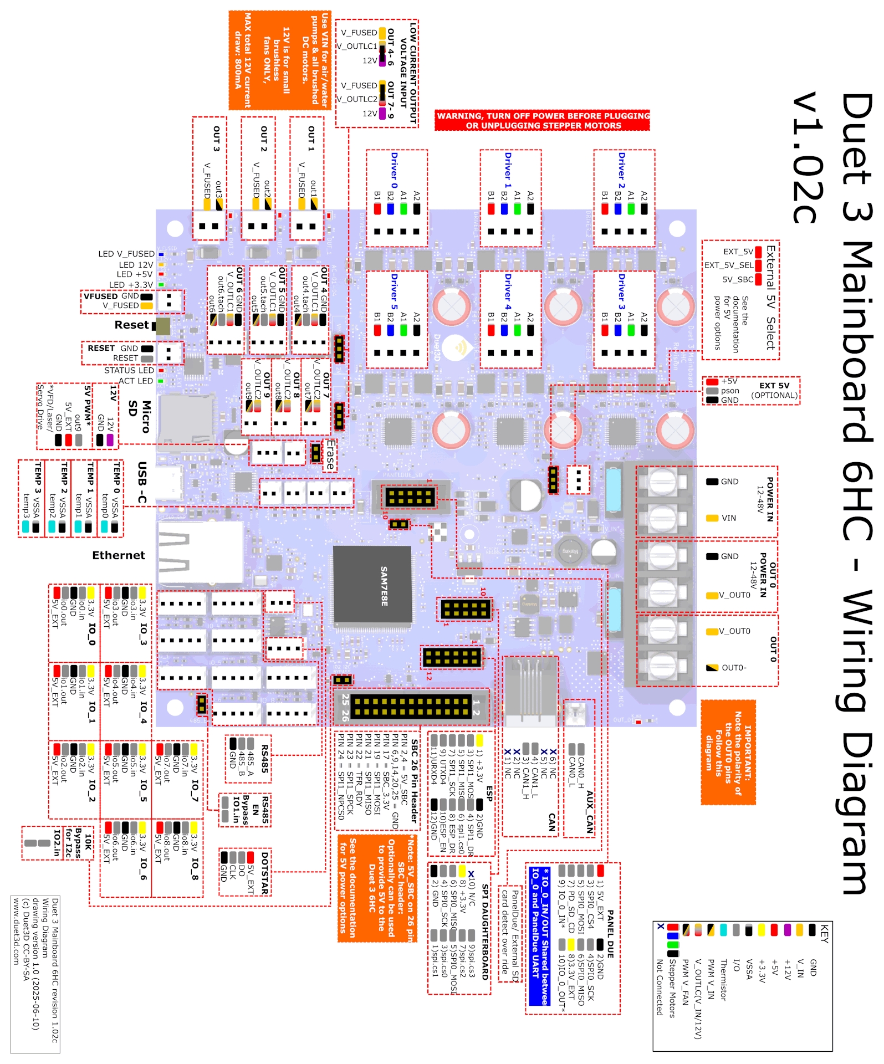
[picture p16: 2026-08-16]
Drawings/8 Wiring Diagrams/duet_3_6hc_1.02_pinout.png

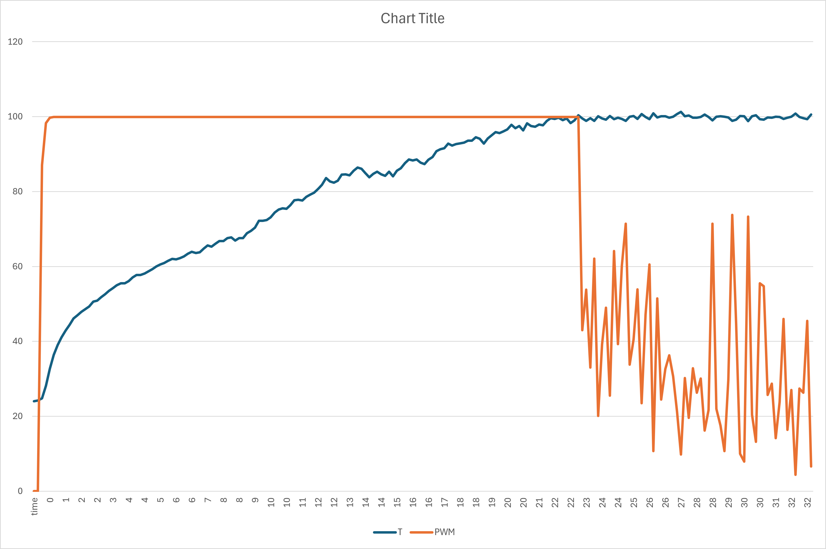
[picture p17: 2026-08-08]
docs/images/Chamber Heating 260806.png

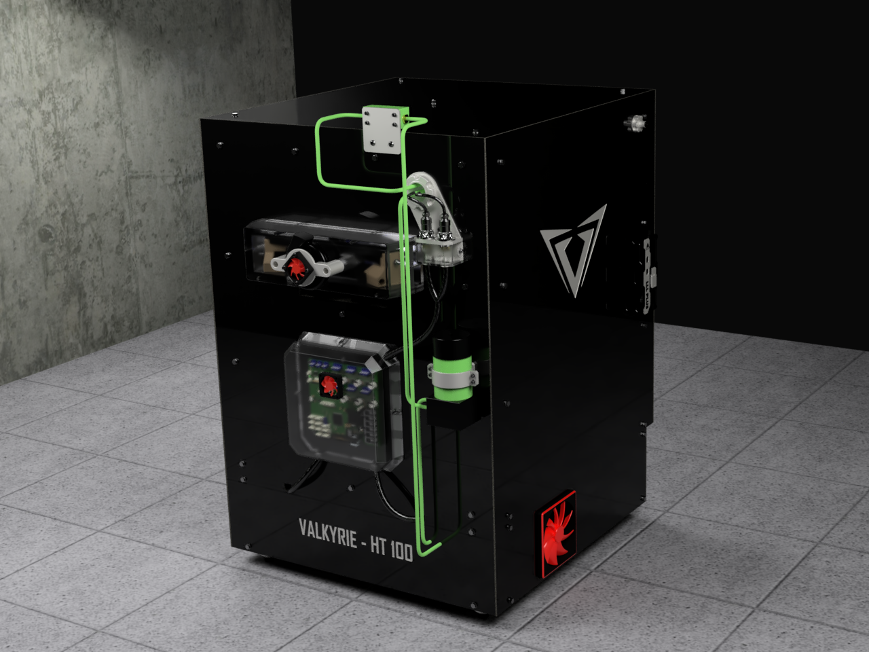
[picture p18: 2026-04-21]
docs/images/V2_Valkyrie_HT100_26002.png

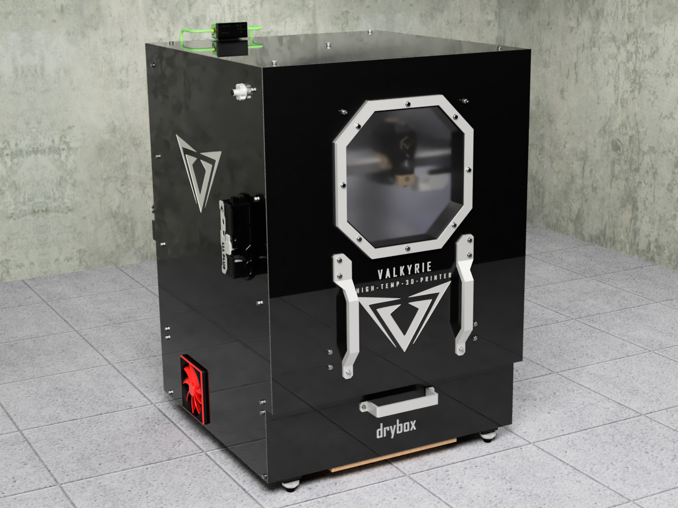
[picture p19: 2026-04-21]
docs/images/V2_Valkyrie_HT100_26001.png

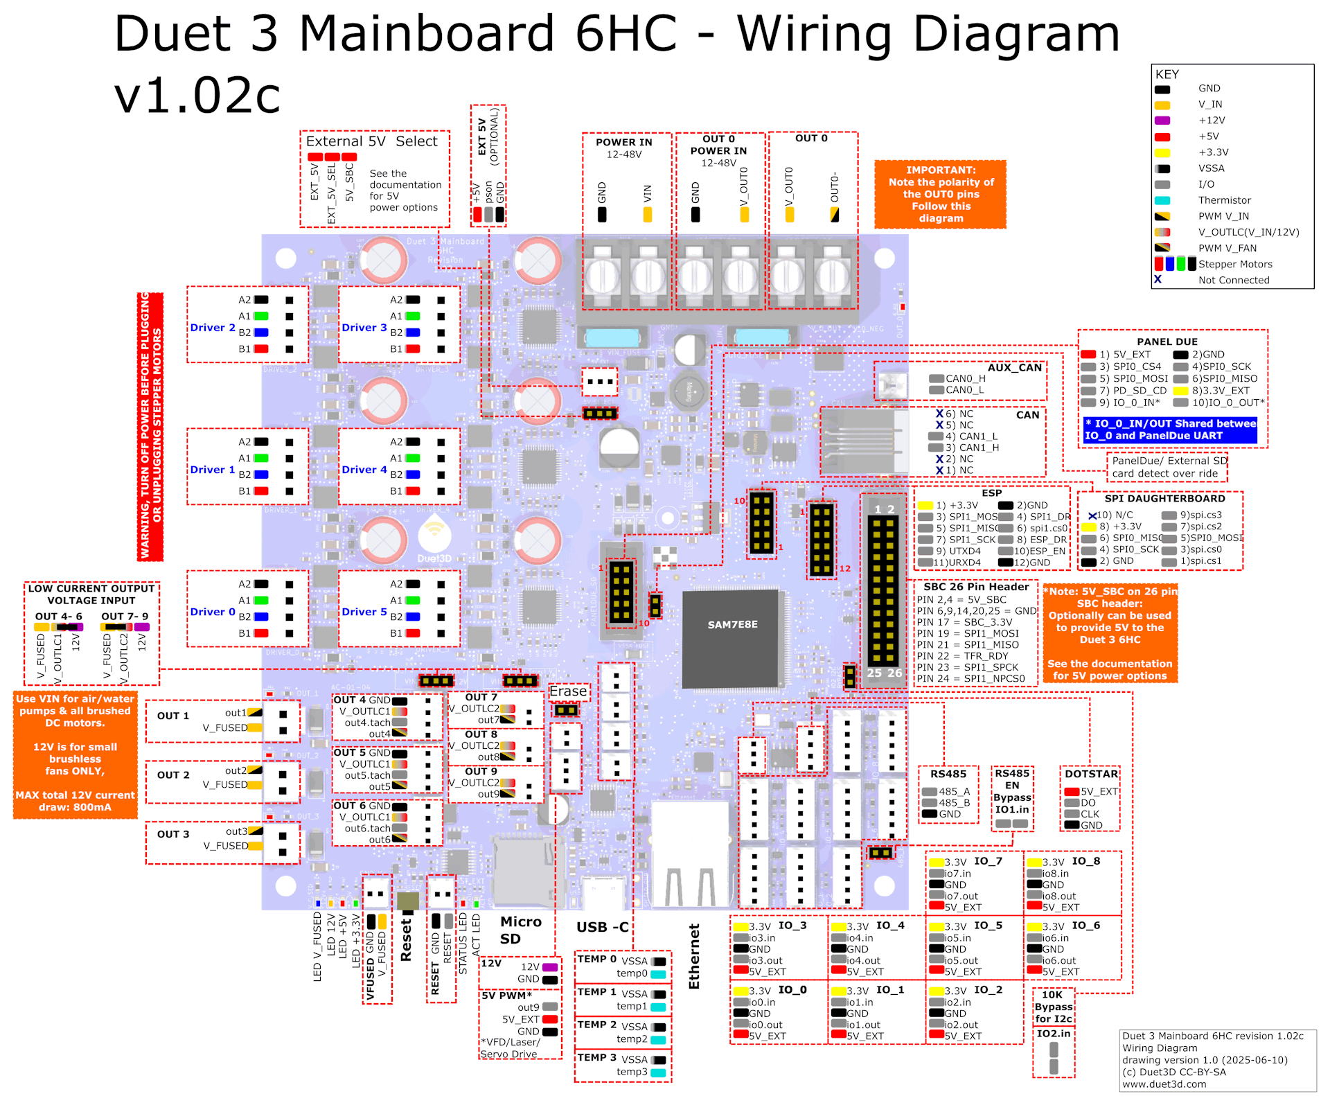
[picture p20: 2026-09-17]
docs/images/duet_3_mb6hc_1.02.png

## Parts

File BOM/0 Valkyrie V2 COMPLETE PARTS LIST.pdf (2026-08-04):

## VALKYRIE V2 - HW BOM

BOM Qty Type Part Required | Pack Order Qty | Pack Price *Cost Price $USD $USD Order Link Supplier Pack Size DIN / ISO
Bearing 04.5 mm Bearing Ball Mothend 1 | 1 | $ 4 $ 4 OD: 4.5mm G100 - N: 10PCS (https://s.click.aliexpress.com/e/_c2wVuKPT) Gosenballs 10
Bearing 05x16x5 Bearing 625ZZ 31 | 4 | $ 5 $ 20 625ZZ - 10PCS (https://s.click.aliexpress.com/e/_c42ABeod) APE 10
Bearing 06x17x6 Bearing F606ZZ 24 | 3 | $ 8 $ 24 F606ZZ - 10PCS (https://s.click.aliexpress.com/e/_c3NPtXxJ) APE 10
Bearing 08x16x5 Bearing 688ZZ 2 | 1 | $ 5 $ 5 688ZZ - 10PCS (https://s.click.aliexpress.com/e/_c42ABeod) APE 10
Bearing 16x400 Draw Slides Drybox 2 | 1 | $ 18 $ 18 C: Buffer 16in - 40cm (https://www.aliexpress.com/item/4001085251691.html) Naierdi 2 (https://s.click.aliexpress.com/e/_9gB9LL)
Bearing M4x10mm Ball Bearing tapped 3 | 1 | $ 5 $ 5 M4x10 Ball Bearing - 20PCS (https://s.click.aliexpress.com/e/_c3xSGcev) Mellow 3D 20
Bearing MGN 12H 350 Linear Rail 3 | 3 | $ 42 $ 126 C: L350 - MGN12H - PL Light (https://s.click.aliexpress.com/e/_c3WYOqRb) CNA 1
Bearing MGN 12H 400 Linear Rail 2 | 2 | $ 38 $ 76 C: L400 - MGN12H - PL Light (https://s.click.aliexpress.com/e/_c3WYOqRb) CNA 1
Bearing MGN 9H 400 Linear Rail 1 | 1 | $ 36 $ 36 C: L400 - MGN9H - PL Medium (https://s.click.aliexpress.com/e/_c3WYOqRb) CNA 1
Electrical Buffer - LLL Plus Filament Buffer 1 | 1 | $ 45 $ 45 Color: LLL Plus Buffer (https://s.click.aliexpress.com/e/_c31WIyQR) Mellow 3D 1
Electrical Cable 14AWG Black 2 | 1 | $ 3 $ 3 Black - 2M - AWG 14 (https://s.click.aliexpress.com/e/_c3YBJ7iN) Mechatrix Store 2
Electrical Cable 14AWG Red 2 | 1 | $ 3 $ 3 Red - 2M - AWG 14 (https://s.click.aliexpress.com/e/_c3YBJ7iN) Mechatrix Store 2
Electrical Cable 18AWG Black 5 | 1 | $ 1 $ 1 Black - 5M - 18AWG (https://s.click.aliexpress.com/e/_c4dxXCIr) Mechatrix Store 5
Electrical Cable 18AWG Blue 2 | 1 | $ 1 $ 1 Blue - 2M - 18AWG (https://s.click.aliexpress.com/e/_c4dxXCIr) Mechatrix Store 2
Electrical Cable 18AWG Green 2 | 1 | $ 1 $ 1 Green - 2M - 18AWG (https://s.click.aliexpress.com/e/_c4dxXCIr) Mechatrix Store 2
Electrical Cable 18AWG Red 5 | 1 | $ 1 $ 1 Red - 5M - 18AWG (https://s.click.aliexpress.com/e/_c4dxXCIr) Mechatrix Store 5
Electrical Cable 18AWG White 2 | 1 | $ 1 $ 1 White - 2M - 18AWG (https://s.click.aliexpress.com/e/_c4dxXCIr) Mechatrix Store 2
Electrical Cable 22AWG Black 7 | 1 | $ 1 $ 1 Black - 10M - 22AWG (https://s.click.aliexpress.com/e/_c4dxXCIr) Mechatrix Store 10
Electrical Cable 22AWG Blue 7 | 1 | $ 1 $ 1 Blue - 10M - 22AWG (https://s.click.aliexpress.com/e/_c4dxXCIr) Mechatrix Store 10
Electrical Cable 22AWG Red 7 | 1 | $ 1 $ 1 Red - 10M - 22AWG (https://s.click.aliexpress.com/e/_c4dxXCIr) Mechatrix Store 10
Electrical Cable 22AWG White 5 | 1 | $ 1 $ 1 White - 5M - 22AWG (https://s.click.aliexpress.com/e/_c4dxXCIr) Mechatrix Store 5
Electrical Cable 22AWG Yellow 5 | 1 | $ 1 $ 1 Yellow - 5M - 22AWG (https://s.click.aliexpress.com/e/_c4dxXCIr) Mechatrix Store 5
Electrical Cable 24AWG Black 2 | 1 | $ 1 $ 1 Black - 2M - 24AWG (https://s.click.aliexpress.com/e/_c4dxXCIr) Mechatrix Store 5
Electrical Cable 24AWG Blue 2 | 1 | $ 1 $ 1 Blue - 2M - 24AWG (https://s.click.aliexpress.com/e/_c4dxXCIr) Mechatrix Store 5
Electrical Cable 24AWG Green 2 | 1 | $ 1 $ 1 Green - 2M - 24AWG (https://s.click.aliexpress.com/e/_c4dxXCIr) Mechatrix Store 5
Electrical Cable 24AWG White 2 | 1 | $ 1 $ 1 White - 2M - 24AWG (https://s.click.aliexpress.com/e/_c4dxXCIr) Mechatrix Store 5
Electrical Cable AC 18AWG Blue 600V 200C 2 | 1 | $ 5 $ 5 Blue - 5M - 18AWG (https://s.click.aliexpress.com/e/_c3ISQAPh) Mechatrix Store 1
Electrical Cable AC 18AWG Brown 600V 200C 2 | 1 | $ 5 $ 5 Brown - 5M - 18AWG (https://s.click.aliexpress.com/e/_c3ISQAPh) Mechatrix Store 1
Electrical Cable AC 18AWG Green 600V 200C 2 | 1 | $ 5 $ 5 Green - 5M - 18AWG (https://s.click.aliexpress.com/e/_c3ISQAPh) Mechatrix Store 1
Electrical Cable Connector JST PH 2-Pin 2 | 1 | $ 2 $ 2 C: Straight pin socket PQ: 10set Pins: 2P (https://s.click.aliexpress.com/e/_c4nPpAD9) ZSDZFYLLK 10
Electrical Cable Connector JST PH 4-Pin 1 | 1 | $ 2 $ 2 C: Straight pin socket PQ: 10set Pins: 4P (https://s.click.aliexpress.com/e/_c4nPpAD9) ZSDZFYLLK 10
Electrical Cable Connector JST PH 6-Pin 1 | 1 | $ 2 $ 2 C: Straight pin socket PQ: 10set Pins: 6P (https://s.click.aliexpress.com/e/_c4nPpAD9) ZSDZFYLLK 10
Electrical Cable Heat Shrink Tube 2:1 3mm 1 | 1 | $ 1 $ 1 Color: black - ID: 3mm - L: 1M (https://s.click.aliexpress.com/e/_c3p4OtLd) Mechatrix Store 1
Electrical Cable Heat Shrink Tube 2:1 4mm 1 | 1 | $ 1 $ 1 Color: black - ID: 4mm - L: 1M (https://s.click.aliexpress.com/e/_c3p4OtLd) Mechatrix Store 1
Electrical Cable Heat Shrink Tube 2:1 8mm 1 | 1 | $ 1 $ 1 Color: black - ID: 8mm - L: 1M (https://s.click.aliexpress.com/e/_c3p4OtLd) Mechatrix Store 1
Electrical Cable Sleeve Braided PET 5 | 1 | $ 4 $ 4 Color: Black Silver - L: 5M (https://www.aliexpress.com/item/1005007376443518.html) Mechatrix Store 5
Electrical Cable tie 80 x 2.5mm 150C rated 1 | 1 | $ 1 $ 1 PLT1M-C76 (https://www.digikey.co.nz/en/products/detail/panduit-corp/PLT1M-C702Y/1306798) Digikey 1
Electrical Control Board Super8/Duet 3 6hc 1 | 1 | $ 148 $ 148 Color: Duet 3 6HC (https://s.click.aliexpress.com/e/_c4SPo8x7) XJW TECH 1
Electrical DC 5.5x2.1mm Power Jack 1M 22AWG 1 | 1 | $ 1 $ 1 Color: Black 22AWG Pins: 0.5m (https://s.click.aliexpress.com/e/_c3AWAu37) ACPOWERCORD 1
Electrical DHT 22 temp/humid sensor 1 | 1 | $ 12 $ 12 C: 1PC DHT22 AM2302 (https://s.click.aliexpress.com/e/_c3GrYLJR) Wxinko ES 1
Electrical DIN Rail + terminal block kit UK2.5 1 | 1 | $ 34 $ 34 Din Rail Terminal Block (https://s.click.aliexpress.com/e/_c43Ypp7z) ZSDZFYLLK 1
Electrical ESP32 + Expansion Board 1 | 1 | $ 17 $ 17 ESP32 + Expansion Board Combo (https://s.click.aliexpress.com/e/_c3pEjVRB) EZ-Electro 1
Electrical Fan 12V 06025 Drybox 1 | 1 | $ 9 $ 9 SUNON 6025 (https://s.click.aliexpress.com/e/_c3qrCpN5) SXDOOL 1
Electrical Fan 12V 09238 Chamber 1 | 1 | $ 11 $ 11 Sunon PSD1209PMB1-A (https://s.click.aliexpress.com/e/_c3Fw0Knb) SXDOOL 1
Electrical Fan 12V 12025 Radiator LC 1 | 1 | $ 8 $ 8 Color: RGB Rainbow-B (https://s.click.aliexpress.com/e/_c3bsP885) Manmu 1
Electrical Fan 12V CPAP Blower ROBO 1 | 1 | $ 11 $ 11 Color: 20N704V170 (https://s.click.aliexpress.com/e/_c3gyR3k7) VCR Store 1
Electrical Fan 24V 04010 MB CPU Cooler 2 | 2 | $ 5 $ 10 Size: 24V (https://s.click.aliexpress.com/e/_c3mx73QL) Mellow 3D 1
Electrical GX20 flange mount & Plug 10pin 1 | 1 | $ 3 $ 3 Color: 10Pin (https://s.click.aliexpress.com/e/_c3WyUNHL) MannHwa 2
Electrical GX20 flange mount & Plug 6pin 1 | 1 | $ 3 $ 3 Color: 6Pin (https://s.click.aliexpress.com/e/_c3WyUNHL) MannHwa 2
Electrical HDC-HE-10core HD connector female 1 | 1 | $ 5 $ 5 Color: 10 female core (https://s.click.aliexpress.com/e/_c38RQspz) Shop4055013 1
Electrical HDC-HE-10core HD connector male 1 | 1 | $ 5 $ 5 Color: 10 male core (https://s.click.aliexpress.com/e/_c38RQspz) Shop4055013 1
Electrical HDC-HE-6core HD connector female 2 | 2 | $ 4 $ 9 Color: 6 female core (https://s.click.aliexpress.com/e/_c38RQspz) Shop4055013 1
Electrical HDC-HE-6core HD connector male 2 | 2 | $ 4 $ 9 Color: 6 male core (https://s.click.aliexpress.com/e/_c38RQspz) Shop4055013 1
Electrical Heater - Buildplate 750w Silicon Heater 1 | 1 | $ 30 $ 30 310 220V(110V) 750W NO 3M! (https://s.click.aliexpress.com/e/_c3ucCn4R) 3D-Future Store 1
Electrical Heater - Nozzle Heater 24v 70W 1 | 1 | $ 4 $ 4 Size: 24V (https://s.click.aliexpress.com/e/_c3fEINlt) Mellow 3D 1
Electrical Heater - PTC 220V 350W Drybox 1 | 1 | $ 14 $ 14 Color: 220V 24V 350W (https://s.click.aliexpress.com/e/_c4NTrrnn) Tony Tang Store 1
Electrical Heater - PTC 220V 750W Chamber 1 | 1 | $ 18 $ 18 220V 750W Electric Heater PTC (https://s.click.aliexpress.com/e/_c2ygycYl) Tony Tang Store 1
Electrical Lighting - 24v led strip 5M 1 | 1 | $ 6 $ 6 Color: DC 24V - L: 5M (https://s.click.aliexpress.com/e/_c2uZPf8t) Dengsum 1
Electrical Load Cell 5kg 1 | 1 | $ 4 $ 4 Adafruit Industries LLC 4541 (https://www.digikey.co.nz/en/products/detail/adafruit-industries-llc/4541/12323573) Digikey 1
Electrical Load cell amplifier HX711 1 | 1 | $ 12 $ 12 1pcs HX711 (https://s.click.aliexpress.com/e/_c4kNyBWv) Shenzhen MS 1
Electrical Nema 17 40mm Z motor 3 | 1 | $ 46 $ 46 C: 17HS16 2004S1 (https://s.click.aliexpress.com/e/_c4CALJIH) STEPPERONLINE 3
Electrical Nema 17 48 S55 AB motor 2 | 2 | $ 23 $ 45 C: 17HS19-2504S (https://s.click.aliexpress.com/e/_c3DzwoAD) STEPPERONLINE 1
Electrical Power Fuse holder 15A 1 | 1 | 4.82 $ 5 C: RT14-20 Fuse Holder AMP: 10A380V (https://s.click.aliexpress.com/e/_c3hqcXl3) XS MALL 1
Electrical Power IEC 2 | 2 | $ 4 $ 8 Digikey 1
Electrical Power IEC extension lead 1 | 1 | 10 $ 10 Color: 0.5m ACPOWERCORD 1
Electrical Power Rocker switch AC 15A 1 | 1 | 10 $ 10 Digikey 1
Electrical PSU 12V DC 75W meanwell 1 | 1 | 16 $ 16 Power (W): LRS-75-12 (https://s.click.aliexpress.com/e/_c3BBmwdR) MEANWELL 1
Electrical PSU 24V DC 350W meanwell 1 | 1 | 33.7 $ 34 Output Voltage: 24V Power: LRS-350 (https://s.click.aliexpress.com/e/_c3Ou6gqJ) STEPPERONLINE 1
Electrical Rubber Gromet 14mm 6 | 1 | $ 6 $ 6 Inner Diameter: 14mm (40Pcs) (https://s.click.aliexpress.com/e/_c3FXGdA3) DMJ Store 40
Electrical Solid State Relay SSR 3 | 3 | $ 15 $ 46 DC5-24V Solid State Relay (https://www.aliexpress.com/item/1005007567533885.html) Mellow 3D 1
Electrical Temp Sensor PT 1000 1 | 1 | $ 12 $ 12 HT PT1000 Thermistor (https://s.click.aliexpress.com/e/_c2QW6ybb) Mellow 3D 1
Electrical Thermal Fuse 95C 1 | 1 | $ 4 $ 4 C: Ceramics-10A T: 95C (https://s.click.aliexpress.com/e/_c33Nzeup) ETERNALFAR 1
V2 BETA | 1 of 2

## VALKYRIE V2 - HW BOM

BOM Qty Type Part Required | Pack Order Qty | Pack Price *Cost Price $USD $USD Order Link Supplier Pack Size DIN / ISO
Fastener 05x08x1 Precision Shim 30 | 1 | $ 3 $ 3 ID: M5x8x50PCS OD: 1mm (https://s.click.aliexpress.com/e/_c4050O4H) TINGOO HS 50 988
Fastener 05x10 D5 Shaft Collar DIN 705 1 | 1 | $ 4 $ 4 ID: 5x10x6xM3 (https://s.click.aliexpress.com/e/_c4sg0aCl) Hui Xing HW 1 705
Fastener 06x12x1 Precision Shim 36 | 1 | $ 3 $ 3 ID: M6x12x50PCS OD: 1mm (https://s.click.aliexpress.com/e/_c4050O4H) TINGOO HS 50 988
Fastener 08x12x1 Precision Shim 2 | 1 | $ 3 $ 3 ID: M8x12x50PCS OD: 1mm (https://s.click.aliexpress.com/e/_c4050O4H) TINGOO HS 50 988
Fastener M3 Nut DIN 934 64 | 2 | $ 2 $ 5 Size: M3 50pcs (https://s.click.aliexpress.com/e/_c4mdY2jp) NINDEJIN 50 934
Fastener M3 Nut Hammer 74 | 5 | $ 2 $ 10 Size M3-20 30Pcs (https://s.click.aliexpress.com/e/_c3b4Davl) NINDEJIN 20
Fastener M3 Washer DIN 125 110 | 2 | $ 2 $ 4 ID: M3x7x0.5 100pcs (https://s.click.aliexpress.com/e/_c2QiBj4r) NINDEJIN 100 125
Fastener M3x05 Set Screw DIN 913 7 | 1 | $ 2 $ 2 Size: M3 50pcs - Length: 5mm (https://s.click.aliexpress.com/e/_c44T4XP5) NINDEJIN 50 913
Fastener M3x08 BH ISO 7380 13 | 1 | $ 3 $ 3 Size: M3 50pcs - Length: 8mm (https://s.click.aliexpress.com/e/_c3cQ78oF) NINDEJIN 50 912
Fastener M3x08 FH DIN 7991 6 | 1 | $ 2 $ 2 Size: M3 20pcs - Length: 8mm (https://s.click.aliexpress.com/e/_c4DakQer) NINDEJIN 20 7991
Fastener M3x08 SH DIN 912 127 | 5 | $ 2 $ 12 D: M3 30pcs - Length: 8mm (https://s.click.aliexpress.com/e/_c3uaTngr) NINDEJIN 30 912
Fastener M3x10 SH DIN 912 55 | 2 | $ 3 $ 5 D: M3 30pcs - Length: 10mm (https://s.click.aliexpress.com/e/_c3uaTngr) NINDEJIN 30 912
Fastener M3x12 FH DIN 7991 6 | 1 | $ 3 $ 3 Size: M3 20pcs - Length: 12mm (https://s.click.aliexpress.com/e/_c4DakQer) NINDEJIN 20
Fastener M3x12 SH DIN 912 18 | 1 | $ 3 $ 3 D: M3 30pcs - Length: 12mm (https://s.click.aliexpress.com/e/_c3uaTngr) NINDEJIN 30 912
Fastener M3x20 SH DIN 912 13 | 1 | $ 3 $ 3 D: M3 30pcs - Length: 20mm (https://s.click.aliexpress.com/e/_c3uaTngr) NINDEJIN 30 912
Fastener M4 Nut DIN 934 24 | 1 | $ 3 $ 3 Size: M4 50pcs (https://s.click.aliexpress.com/e/_c4EKwdYX) NINDEJIN 50 934
Fastener M4 Nut Locknut DIN 985 18 | 1 | $ 3 $ 3 S: M4 30pcs - C: 304 ss (https://s.click.aliexpress.com/e/_c3nvXY3Z) NINDEJIN 30 985
Fastener M4 Washer DIN 125 41 | 1 | $ 2 $ 2 ID: M4x9x0.8 100pcs (https://s.click.aliexpress.com/e/_c3RABFfV) NINDEJIN 100 25
Fastener M4x12 FH DIN 7991 8 | 1 | $ 2 $ 2 Size: M4 20pcs - Length: 12mm (https://s.click.aliexpress.com/e/_c3xJuayx) NINDEJIN 20 7991
Fastener M4x14 SH DIN 912 16 | 1 | $ 3 $ 3 D: M4 20pcs - Length: 14mm (https://s.click.aliexpress.com/e/_c3dDPoZd) NINDEJIN 20 912
Fastener M4x16 D5 Shoulder Screw 6 | 2 | $ 3 $ 6 Size: 5Pcs 5-M4 - Length: 16mm (https://s.click.aliexpress.com/e/_c3I5Vat9) TINGOO HS 5 7379
Fastener M4x25 FH DIN 7991 9 | 1 | $ 3 $ 3 Size: M4 20pcs - Length: 25mm (https://s.click.aliexpress.com/e/_c4s1l6ox) NINDEJIN 20 7991
Fastener M4x35 HEX DIN 933 5 | 1 | $ 2 $ 2 Size: M4 10pcs - Length: 35mm (https://s.click.aliexpress.com/e/_c3LX9DB9) NINDEJIN 10 933
Fastener M4x50 FH DIN 7991 6 | 1 | $ 3 $ 3 Size: M4 20pcs - Length: 50mm (https://s.click.aliexpress.com/e/_c4s1l6ox) NINDEJIN 20 7991
Fastener M4x55 D5 Shoulder Screw 4 | 1 | $ 6 $ 6 S: 5PCS 5-M4 - L: 55mm (https://s.click.aliexpress.com/e/_c3seEKjb) TINGOO HS 5 7379
Fastener M5 Nut DIN 934 32 | 1 | $ 3 $ 3 Size: M5 50pcs (https://s.click.aliexpress.com/e/_c4EKwdYX) NINDEJIN 50 934
Fastener M5 Nut Hammer 200 | 7 | $ 2 $ 14 Size M5-20 30Pcs (https://s.click.aliexpress.com/e/_c3b4Davl) NINDEJIN 30
Fastener M5 Nut Locknut 13 | 1 | $ 3 $ 3 S: M5 30pcs - C: 304 ss (https://s.click.aliexpress.com/e/_c3nvXY3Z) NINDEJIN 30 985
Fastener M5 Washer DIN 125 188 | 2 | $ 1 $ 3 ID: M5x9x1 100pcs (https://s.click.aliexpress.com/e/_c3RABFfV) NINDEJIN 100 125
Fastener M5x10 BH ISO 7380 169 | 19 | $ 2 $ 47 Size: M5 10pcs - Length: 10mm (https://s.click.aliexpress.com/e/_c3FJZ5th) NINDEJIN 10 7380
Fastener M5x25 BH ISO 7380 14 | 2 | $ 3 $ 6 Size: M5 10pcs - Length: 25mm (https://s.click.aliexpress.com/e/_c3cQ78oF) NINDEJIN 10 7380
Fastener M5x30 HEX DIN 933 5 | 1 | $ 2 $ 2 Size: M5 10pcs - Length: 30mm (https://s.click.aliexpress.com/e/_c3LX9DB9) NINDEJIN 10 933
Fastener M5x40 HEX DIN 933 44 | 5 | $ 3 $ 16 Size: M5 10pcs - Length: 40mm (https://s.click.aliexpress.com/e/_c3LX9DB9) NINDEJIN 10 933
Fastener M5x55 HEX DIN 933 17 | 2 | $ 3 $ 6 Size: M5 10pcs - Length: 55mm (https://s.click.aliexpress.com/e/_c3LX9DB9) NINDEJIN 10 933
Fastener M6x10 BH ISO 7380 42 | 4 | $ 2 $ 8 Size: M6 10pcs - Length: 10mm (https://s.click.aliexpress.com/e/_c3FJZ5th) NINDEJIN 10 7380
Kinematics GT2 Gear 20T(5mm)-80T(5mm)-W:6-200 3 | 3 | $ 16 $ 48 BD:20T(5mm)-80T(5mm)-W:6mm-200 (https://s.click.aliexpress.com/e/_c3SWMl29) POWGE 1
Kinematics GT2 Pulley 20T 11mm 6 | 1 | $ 20 $ 20 BD: 5mm BW: 10mm N: 10PCS (https://s.click.aliexpress.com/e/_c3Fj3Z4D) POWGE 10
Kinematics GT2 Timing Belt Z EPDM 9mm 10 | 1 | $ 40 $ 40 W: Red 9mm-EPDM L: 10M (https://s.click.aliexpress.com/e/_c3PsUJcZ) POWGE 5
Kinematics GT2 Timing Pulley 16T 11mm 2 | 1 | $ 7 $ 7 BD: 5mm BW: 10mm PCS: 2 (https://s.click.aliexpress.com/e/_c2wfnsB3) POWGE 2
Kinematics GT2 Timing Pulley 16T 7mm 3 | 1 | $ 6 $ 6 BD: 5mm BW: 6mm PCS: 3 (https://s.click.aliexpress.com/e/_c2wfnsB3) POWGE 3
Magnet Magnet 06x05 Z Probe 6 | 1 | $ 9 $ 9 C: 50pcs 6x5mm (https://s.click.aliexpress.com/e/_c313FTTJ) HW Store 50
Magnet Magnet 15x03 Buildplate 36 | 1 | $ 60 $ 60 Color: 50pcs 15x3mm (https://s.click.aliexpress.com/e/_c3DVJucF) HW Store 50
Magnet Magnet 20x05 Doorlift 6 | 1 | $ 10 $ 10 Color: 6PCS S: A20 (https://s.click.aliexpress.com/e/_c39y0zzF) SZ-Ming 6
Magnet Magnet Keeper 20x03 Doorlift 6 | 2 | $ 2 $ 4 Size: 5pcs M4 (https://s.click.aliexpress.com/e/_c3h7Zh5j) TINGOO HS 5
Plumbing LC - 04mm ID Barb 1/4" 4 | 4 | $ 2 $ 9 S: 4mm Barb - TS: 1/4" (https://s.click.aliexpress.com/e/_c30wfREH) EES Store 1 (https://s.click.aliexpress.com/e/_c3L3d1ir)
Plumbing LC - 06mm ID Barb 1/4" 4 | 4 | $ 2 $ 8 S: 6mm Barb - TS: 1/4" (https://s.click.aliexpress.com/e/_c30wfREH) EES Store 1
Plumbing LC - Flowmeter 1 | 1 | $ 31 $ 31 Flow Liquid Monitoring LSJ-ZNBJ (https://s.click.aliexpress.com/e/_c3w69LJf) FREEZEMOD 1
Plumbing LC - M5-4ID Elbow Fitting 2 | 1 | $ 3 $ 3 C: WX-KPC6-M5 (https://www.aliexpress.com/item/1005003339030118.html) ZGUA Store 5
Plumbing LC - Radiator 120mm 1 | 1 | $ 30 $ 30 AS120-T 120mm radiator 22mm (https://s.click.aliexpress.com/e/_c3bbKMFL) SysCooling 1
Plumbing LC - Radiator Extruder 30x30x9.5 1 | 1 | $ 13 $ 13 Color: 30x30 (https://s.click.aliexpress.com/e/_c4PHjpil) Cynzo 1
Plumbing LC - Tubing 4x6 mm IDxOD 5M 3 | 1 | $ 5 $ 5 C: 4x6mm - L: 5M (https://s.click.aliexpress.com/e/_c3LzJrff) ANHI Store 5
Plumbing LC - Tubing 4x6 mm IDxOD 5M 3 | 1 | $ 7 $ 7 C: 6x8mm - L: 5M (https://s.click.aliexpress.com/e/_c3LzJrff) ANHI Store 5
Plumbing LC - Waterpump 1 | 1 | $ 44 $ 44 C: 65mm-Black (https://s.click.aliexpress.com/e/_c2zvHf0p) SysCooling 1
Profile 15x15x1 Aluminum Tube L: 230mm 4 | 2 | $ 4 $ 8 L: 500mm - S: 15x15x1mm (https://s.click.aliexpress.com/e/_c3mGH8Fj) 18th Gw 1
Profile 2020 Joining Plate 90 Deg 2 | 1 | $ 15 $ 15 Color: Silver L - Size: 2020 (4pcs) (https://s.click.aliexpress.com/e/_c2wZSX8N) BULK-MAN 4
Profile 2020 T-Slot X Profile Top Rear 1 | 1 | $ 12 $ 12 Color: L 420mm - 2020 (https://s.click.aliexpress.com/e/_c4rtJlUD) HighQ Store 1
Profile 2020 T-Slot Z Center Rear 1 | 1 | $ 11 $ 11 Color: L 368mm - 2020 (https://s.click.aliexpress.com/e/_c4rtJlUD) HighQ Store 1
Profile 2020 T-Slot Z Center Rear Top 1 | 1 | $ 9 $ 9 Color: L 172mm - 2020 (https://s.click.aliexpress.com/e/_c4rtJlUD) HighQ Store 1
Profile 2028 T-Slot L-Bracket 34 | 4 | $ 5 $ 22 Color: 10PCS 2028 Silver (https://s.click.aliexpress.com/e/_c4E1qB2Z) HTCC Store 10
Profile 2040 T-Slot X Length Profile 4 | 4 | $ 15 $ 60 Color: L 420mm - 2040 (https://s.click.aliexpress.com/e/_c4rtJlUD) HighQ Store 1
Profile 2040 T-Slot Y Length Profile 4 | 4 | $ 16 $ 64 Color: L 480mm - 2040 (https://s.click.aliexpress.com/e/_c4rtJlUD) HighQ Store 1
Profile 2040 T-Slot Z Height Profile 4 | 4 | $ 40 $ 160 Color: L 750mm - 2040 (https://s.click.aliexpress.com/e/_c4rtJlUD) HighQ Store 1
Profile 20x20x1 Aluminum Tube L: 410mm 1 | 1 | $ 4 $ 4 L: 500mm - S: 20x20x1mm (https://s.click.aliexpress.com/e/_c3mGH8Fj) 18th Gw 1
Profile 300x300x3mm - PC Sheet 2 | 1 | $ 18 $ 18 S: 300x300x3mm2 (https://s.click.aliexpress.com/e/_c3suoWc5) Shop110 2
Profile Buildplate Cast AL 5083 8mm 1 | 1 | $ 100 $ 100 Source locally or ask MELLOW (https://s.click.aliexpress.com/e/_c44XY1Gx) Local 1
Profile Buildplate Print Surface Sheet 1 | 1 | $ 25 $ 25 Size: 350x350mm (https://s.click.aliexpress.com/e/_c4XlsLcd) 3D Printing MS 1
Profile Plate - Aluminum for DIN & SSR 2 | 2 | $ 10 $ 19 Color: 200x200mm - S: 3mm 1pc (https://s.click.aliexpress.com/e/_c381BjXN) 18th Gw 1
Profile V2 Insulation Drybox 1 | 1 | $ 12 $ 12 10MM Thermal Insulation (https://s.click.aliexpress.com/e/_c3xzfLHX) 1
Shaft 03x06 Dowel aligning Pin 2 | 1 | $ 1 $ 1 M3x10pcs - 6mm (https://s.click.aliexpress.com/e/_c3kqXzMt) Victor HW 10
Shaft 03x25 Bearing Shaft 2 | 1 | $ 3 $ 3 M3x10pcs - 25mm (https://s.click.aliexpress.com/e/_c3kqXzMt) Victor HW 10
Shaft 05x40 Bearing Shaft 6 | 1 | $ 7 $ 7 M5x40 (20pcs) (https://s.click.aliexpress.com/e/_c3SeE1nf) HGKL 20
Shaft 05x50 Bearing Shaft 6 | 1 | $ 7 $ 7 M5x50 (20pcs) (https://s.click.aliexpress.com/e/_c3SeE1nf) HGKL 20
Shaft 06x30 Bearing Shaft 4 | 1 | $ 7 $ 7 M6x30 (20pcs) (https://s.click.aliexpress.com/e/_c3SeE1nf) HGKL 20
Shaft 06x40 Bearing Shaft 8 | 1 | $ 7 $ 7 M6x40 (20pcs) (https://s.click.aliexpress.com/e/_c3SeE1nf) HGKL 20
Shaft 08x400 Steel Rod - Door Link 1 | 1 | $ 8 $ 8 L: 400 D: 8mm (https://s.click.aliexpress.com/e/_c3cRHpi9) YUNSHUO 1
Spring 07x10 Spring 0.4 WD 2 | 1 | $ 13 $ 13 L: 10mm(10pcs) - WD: 0.4 - OD: 7mm (https://s.click.aliexpress.com/e/_c3TqIw33) AZ-hw 10
Toolpart Brush 40 x12.5 x 9.5mm 1 | 1 | $ 4 $ 4 Nozzle Cleaning Brush (https://s.click.aliexpress.com/e/_c4TkoBx1) FYSETC 1
Toolpart Extruder - BIQU H2 V2X 1 | 1 | $ 35 $ 35 BTT H2 V2X Extruder (https://s.click.aliexpress.com/e/_c4LSWWWD) BIGTREETECH 1
Toolpart Fan Tube CPAP for part air 1 | 1 | $ 11 $ 11 C: Black Closed - ID 17xAD 21.2 - L:1m (https://s.click.aliexpress.com/e/_c4Lh5ETb) ORIGWOOD 1
Toolpart Milk White PTFE Tube 1 | 1 | $ 5 $ 5 ID: ID 2 x OD 4mm L: 3 meter (https://s.click.aliexpress.com/e/_c4b8nTwb) Mellow 3D 1
Toolpart Mothend V2 1 | 1 | $ 48 $ 48 JLC (https://jlccnc.com/) JLC CNC 1
Toolpart NF Crazy-Heater Block Copper 1 | 1 | $ 25 $ 25 Color: Copper (https://s.click.aliexpress.com/e/_c3C2Pacd) Mellow 3D 1
Toolpart Phaetus SiliconCarbide VolcanoNozzle 1 | 1 | $ 25 $ 25 Size: 0.6MM Volcano (https://s.click.aliexpress.com/e/_c3sBWy35) Mellow 3D 1
Toolpart V6 Bimetal Heatbreak 1 | 1 | $ 10 $ 10 Color: Bi-Metal Short (https://s.click.aliexpress.com/e/_c42QxBlt) Lerge 5
Price exl Taxes - exl insulation/paneling *shipping cost may vary | $ | 2,345
V2 BETA | 2 of 2

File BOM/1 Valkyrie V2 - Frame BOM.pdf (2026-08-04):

## VALKYRIE V2 - FRAME BOM

INDEX | Part name | Description | Length | QTY
Support Links: | 2020 T-Slot Profile (https://s.click.aliexpress.com/e/_c4XP5DpL) | X Top Rear | 420 | 1 | DEV TEAM
Buy Me a Coffee (https://ko-fi.com/pro3d) | 2020 T-Slot Profile (https://s.click.aliexpress.com/e/_c4XP5DpL) | Z Center Rear | 368 | 1 | Roy Berntsen
By Patreon (https://www.patreon.com/pro3d) | 2020 T-Slot Profile (https://s.click.aliexpress.com/e/_c4XP5DpL) | Z Center Rear Top | 172 | 1 | Mark Bridgewater
By PayPal (https://www.paypal.com/donate/?hosted_button_id=LZ7RAQGSE4SS8) | 2040 T-Slot Profile (https://s.click.aliexpress.com/e/_c4XP5DpL) | X Length Profile | 420 | 4
| 2040 T-Slot Profile (https://s.click.aliexpress.com/e/_c4XP5DpL) | Y Length Profile | 480 | 4
| 2040 T-Slot Profile (https://s.click.aliexpress.com/e/_c4XP5DpL) | Z Height Profile | 750 | 4
| 2028 L-Bracket | Corner Bracket | | 34
| Joining Plate 90 Deg | Joining plate 90 | | 2
| M5 Nut Hammer Nut | Fastener | | 81
| M5 Nut Locknut | Fastener | | 8
YouTube (https://www.youtube.com/@PRO3DESIGN) | M5 WASHER DIN 125 | Fastener | | 78
| M5x10 BH ISO 7380 | Fastener | | 81
| M5x30 BH ISO 7380 | Fastener | | 4
| M6x10 BH ISO 7380 | Fastener | | 42
Printed Parts Link | V2 Center Z Support Bracket_1x | Print | | 1
| V2 DoorStop_4x | Print/Buy (https://s.click.aliexpress.com/e/_c3waEF0B) | | 4
| V2 Leg Base_4x | Print | | 4
| V2 Leg Nut_4x | Print | | 4

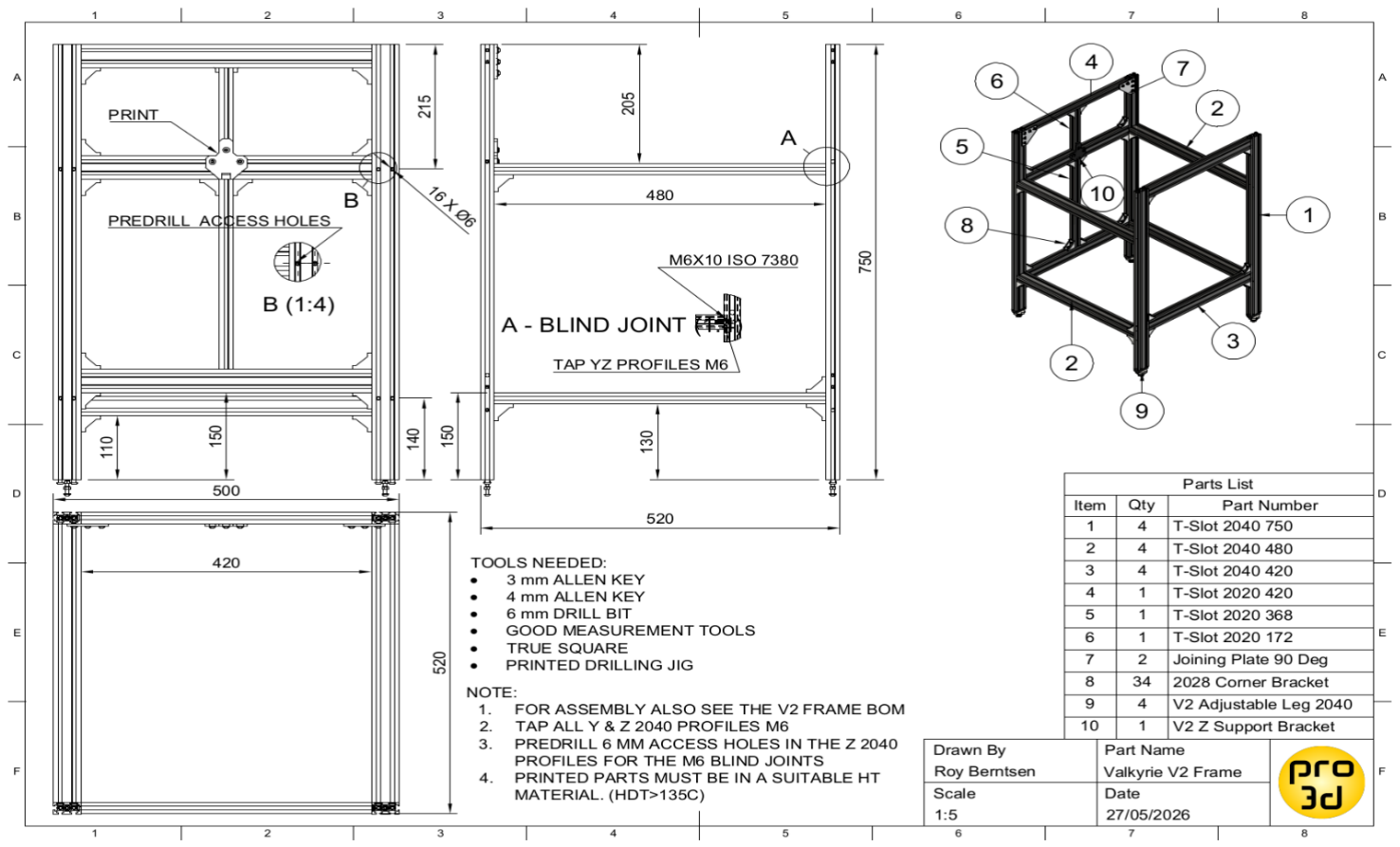
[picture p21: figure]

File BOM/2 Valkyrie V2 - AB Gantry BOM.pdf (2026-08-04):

## VALKYRIE V2 - AB GANTRY BOM

INDEX | Part name | Description

BOM
Quantity
Support Links: | 05x16x5 Bearing 625ZZ | 2 | DEV TEAM
Buy Me a Coffee (https://ko-fi.com/pro3d) | 06x05 Magnet SmCo | 2 | Roy Berntsen
By Patreon (https://www.patreon.com/pro3d) | 06x12x1 Precision Shim | 36 | Mark Bridgewater
By PayPal (https://www.paypal.com/donate/?hosted_button_id=LZ7RAQGSE4SS8) | 06x17x6 Bearing F606ZZ | 24
| 06x30 Bearing Shaft | 4
| 06x40 Bearing Shaft | 8
| GT2 Pulley 16T 11mm | 2
| GT2 Timing Belt AB | 5
| M3 Nut DIN 934 | 24
| M3 Nut Hammer Nut | 32
YouTube (https://www.youtube.com/@PRO3DESIGN) | M3 Washer DIN 125 | 12 | Printed Parts Link
| M3x08 BH ISO 7380 | 8 | V2 Drawings
| M3x08 SH DIN 912 | 48
| M3x10 SH DIN 912 | 12
| M3x12 SH DIN 912 | 6
| M3x20 SH DIN 912 | 2
| M5 LOCK NUT | 2
| M5 Nut DIN 934 | 11
| M5 Nut Hammer Nut | 26
| M5 WASHER DIN 125 | 6
| M5x10 BH ISO 7380 | 34
| M5x25 BH ISO 7380 | 5
| M5x30 HEX ISO 4017 DIN 933 | 2
MGN12H 400 | Preload - Light | 2
MGN9H 400 | Preload - Medium | 1
| Nema 17 48 S55 | 2
V205 AB Brace Bearing Buddy | Printed Parts Link | 2
V205 AB Idler Tension Fork | Print | 2
V205 AB Idler Tension Tower A | Print | 1
V205 AB Idler Tension Tower B | Print | 1
V205 AB Motor Brace | Print | 1
V205 AB Motor Bracket | Print | 1
V205 Idler Bracket Front A | Print | 1
V205 Idler Bracket Front B | Print | 1
V205 Idler Bracket Rear AB | Print | 2
V205 Idler Spacer Rear | Print | 4
V205 Nozzle Brushing Bracket | Print | 1
V205 Nozzle Brushing Bucket | Print | 1
V205 Y Carrier A_1 | Print | 1
V205 Y Carrier A_2 | Print | 1
V205 Y Carrier B_1 | Print | 1
V205 Y Carrier B_2 | Print | 1
V205 Z Sensor Dock | Print | 1
V205 Z Sensor Dock Bracket | Print | 1
V206 20x20x1 AL Tube | Buy/make | 1
V206 Nozzle Brass Brush | Buy | 1
V2 BETA | 1 of 2

## VALKYRIE V2 - AB GANTRY BOM

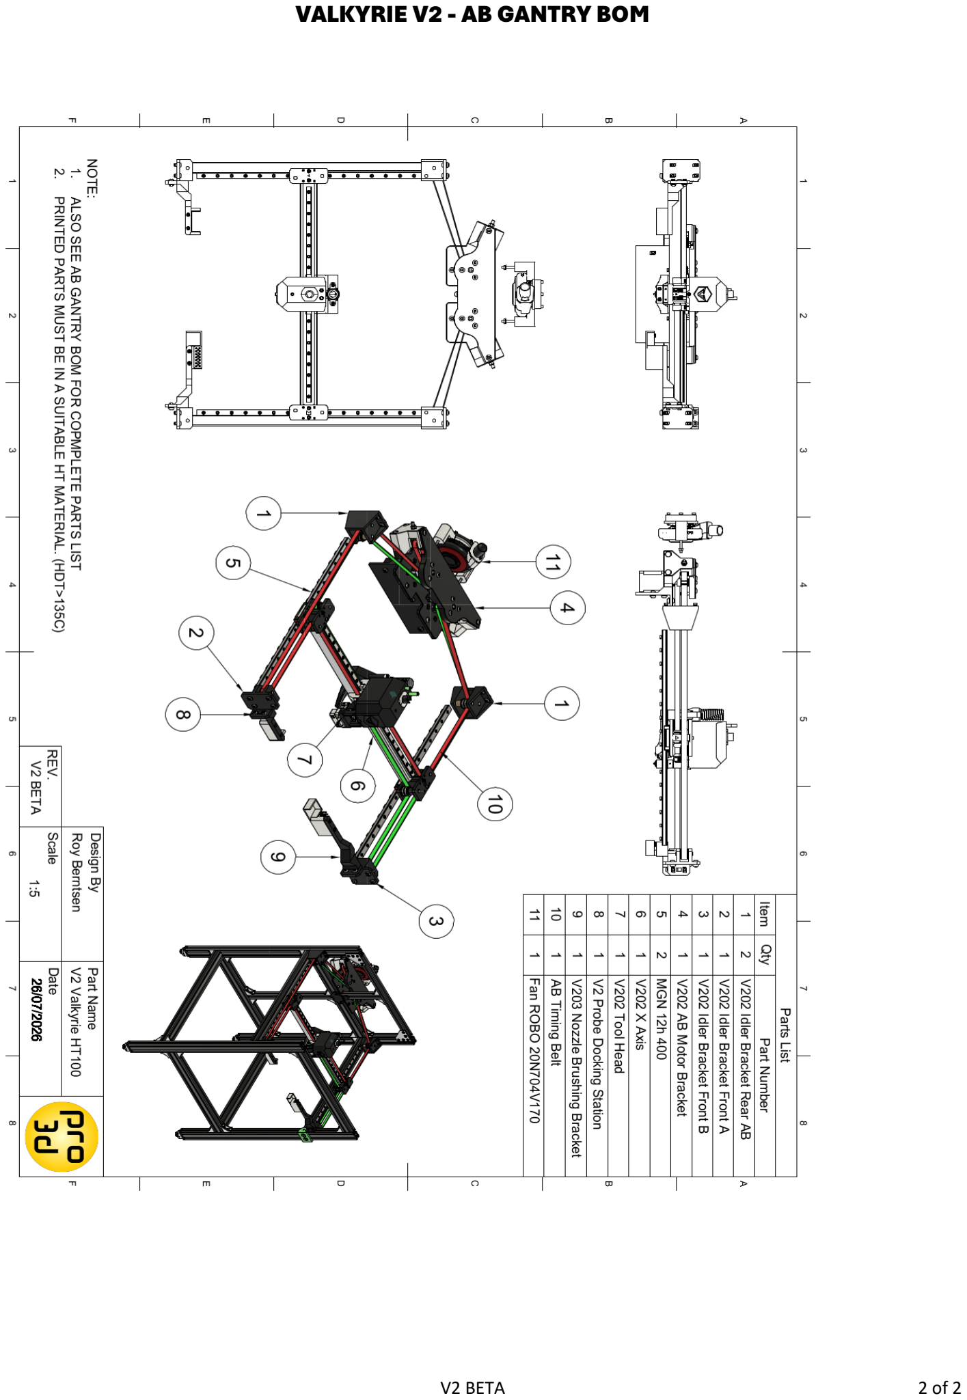
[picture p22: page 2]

V2 BETA | 2 of 2

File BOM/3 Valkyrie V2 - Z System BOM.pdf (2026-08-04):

## VALKYRIE V2 - Z SYSTEM BOM

INDEX | Part name | Description

BOM
Quantity
Support Links: | 03x06 Dowel Aligning Pin | | 2 | DEV TEAM
Buy Me a Coffee (https://ko-fi.com/pro3d) | 03x25 Bearing shaft | tool sensor | 1 | Roy Berntsen
By Patreon (https://www.patreon.com/pro3d) | 05x08x1 Precision Shim | bearings | 12 | Mark Bridgewater
By PayPal (https://www.paypal.com/donate/?hosted_button_id=LZ7RAQGSE4SS8) | 05x16x05 625-2ZZ Bearing | idlers & gears | 12
| 05x40 Bearing Shaft | idlers | 3
| 05x50 Bearing Shaft | idlers | 6
| 07x10 Probe Spring | | 1
| Bedplate Cast AL 5083 8mm | 350x350x8 | 1
| Bedplate Heater - 300x300 750w | | 1
| Bedplate Thermal Fuse 165C | | 1
YouTube (https://www.youtube.com/@PRO3DESIGN) | Buildplate Print Plate | Spring steel | 1
| Buildplate Sheet Magnet | 15x3 SmCo | 36
| GT2 EPDM 10mm +135℃ | | 1
| GT2 Gears 20T(5)-80T(5) - W: 6-200 | | 3
| GT2 Pulley 16T 7mm | | 3
| GT2 Pulley 20T 11mm | | 6
| GT2 Timing Belt Z | 9/10 mm | 5
| M3 Nut DIN 934 | | 3
| M3 Nut Hammer Nut | | 42
| M3 Washer DIN 433 | | 35
| M3x08 SH DIN 912 | | 57
| M3x10 SH DIN 912 | | 13
| M3x12 SH DIN 912 | | 2
| M3x20 SH DIN 912 | | 7
| M4 Nut DIN 934 | | 1
| M4 Nut Nylock DIN 985 | | 3
| M4 Ø10 Ball Bearing Tapped | | 3
| M4 Washer DIN 433
| M4x16 HEX DIN 933 | | 1
| M4x25 FH DIN 7991 | | 3
| M4x25 HEX DIN 933 | | 1
| M4x55 D5 L55 Shoulder Screw | | 3
| M5 Nut Hammer Nut | | 17
| M5 Nut Nylock DIN 985 | | 3
| M5 WASHER DIN 125 | | 6
| M5x10 BH ISO 7380 | | 14
| M5x25 BH ISO 7380 | | 3
| M5x30 HEX DIN 933 ISO 4017 | | 3
| MGN12H 350 Linear Rail | | 3
| Stepper Motor Nema 17-55 LS | | 3
| V2 Bed Strain Relief | print | 1
| V2 Tool Sensor Buddy | print | 1
| V2 Tool Sensor Probe | print | 1
| V2 Z Belt Clamp AB | print | 2
| V2 Z Belt Clamp C | print | 1
| V2 Z Carrier A | print | 1
| V2 Z Carrier B | print | 1
| V2 Z Carrier C | print | 1
| V2 Z Gearbox Bracket A | print | 1
| V2 Z Gearbox Bracket B | print | 1
| V2 Z Gearbox Bracket C | print | 1
| V2 Z Gearbox Cover AC | print | 2
| V2 Z Gearbox Cover B | print | 1
| V2 Z Gearbox Dust Cover | print | 3
| V2 Z Idler Tower A | print | 1
| V2 Z Idler Tower B | print | 1
| V2 Z Idler Tower C | print | 1
| V2 Z Idler Tower Pulley Fork | print | 3
V2 BETA | 1 of 1

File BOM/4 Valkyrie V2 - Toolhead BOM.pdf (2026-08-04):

## VALKYRIE V2 - TOOLHEAD BOM

INDEX | Part name | Description

BOM
Quantity
Support Links: | 03x25 Bearing shaft | 1 | DEV TEAM
Buy Me a Coffee (https://ko-fi.com/pro3d) | 06x05 Magnet SmCo | 4 | Roy Berntsen
By Patreon (https://www.patreon.com/pro3d) | 07x10 Spring | 1 | Mark Bridgewater
By PayPal (https://www.paypal.com/donate/?hosted_button_id=LZ7RAQGSE4SS8) | 6702-2Z Bearing | 2
| Extruder - BIQU H2 V2X | 1
| Extruder radiator 30x30x9.5 | 1
Fan CPAP Blower Robo | Fan blower | 1
Fan CPAP Tube | Fan blower tube | 1
Fan ROBO COOLER 12V 4010 fan | Fan axial | 1
| M3 Nut DIN 934 | 8
YouTube (https://www.youtube.com/@PRO3DESIGN) | M3 Washer DIN 125 | 18
| M3x05 Set Screw DIN 913 | 7
| M3x08 FH DIN 7991 | 6
| M3x08 SH DIN 912 | 5
| M3x10 SH DIN 912 | 4
| M3x12 SH DIN 912 | 10
| M4 NUT DIN 934 | 1
| M4 WASHER | 1
| M4x35 HEX DIN 933 | 1
| V205 CPAP Fan Duct | 1
| V205 CPAP ROBO Fan Bracket | 1
| V205 CPAP Swivel Bearing Spacer | 1
| V205 CPAP Swivel Chimney | 1
| V205 CPAP Swivel Clamp | 1
| V205 CPAP Swivel Tube | 1
| V205 Tool Head Cable Channel | 1
| V205 Tool Head Cable Chimney | 1
| V205 Tool Head Cable Clip | 1
| V205 Tool Head Cover | 1
| V205 Tool Head Plate | 1
| V205 Z Sensor House | 1
| V205 Z Sensor Probe | 1
BETA PRELEASE | 1 of 2

## VALKYRIE V2 - TOOLHEAD BOM

Part name | Description BOM
| Quantity
Heater Cartridge 70W | 1
M3x03 Set Screw DIN 913 | 2
M5-6OD Elbow Fitting | 2
Mothblock V2 | 1
Mothend Ball plug Ø4.5 | 1
NF-Crazy Volcano heat block | 1
PT 1000 - 1M | 1
V6 Bimetal Heatbreak | 1
Volcano Nozzle V6 Hardened | 1

## MOTHEND HOTEND BOM

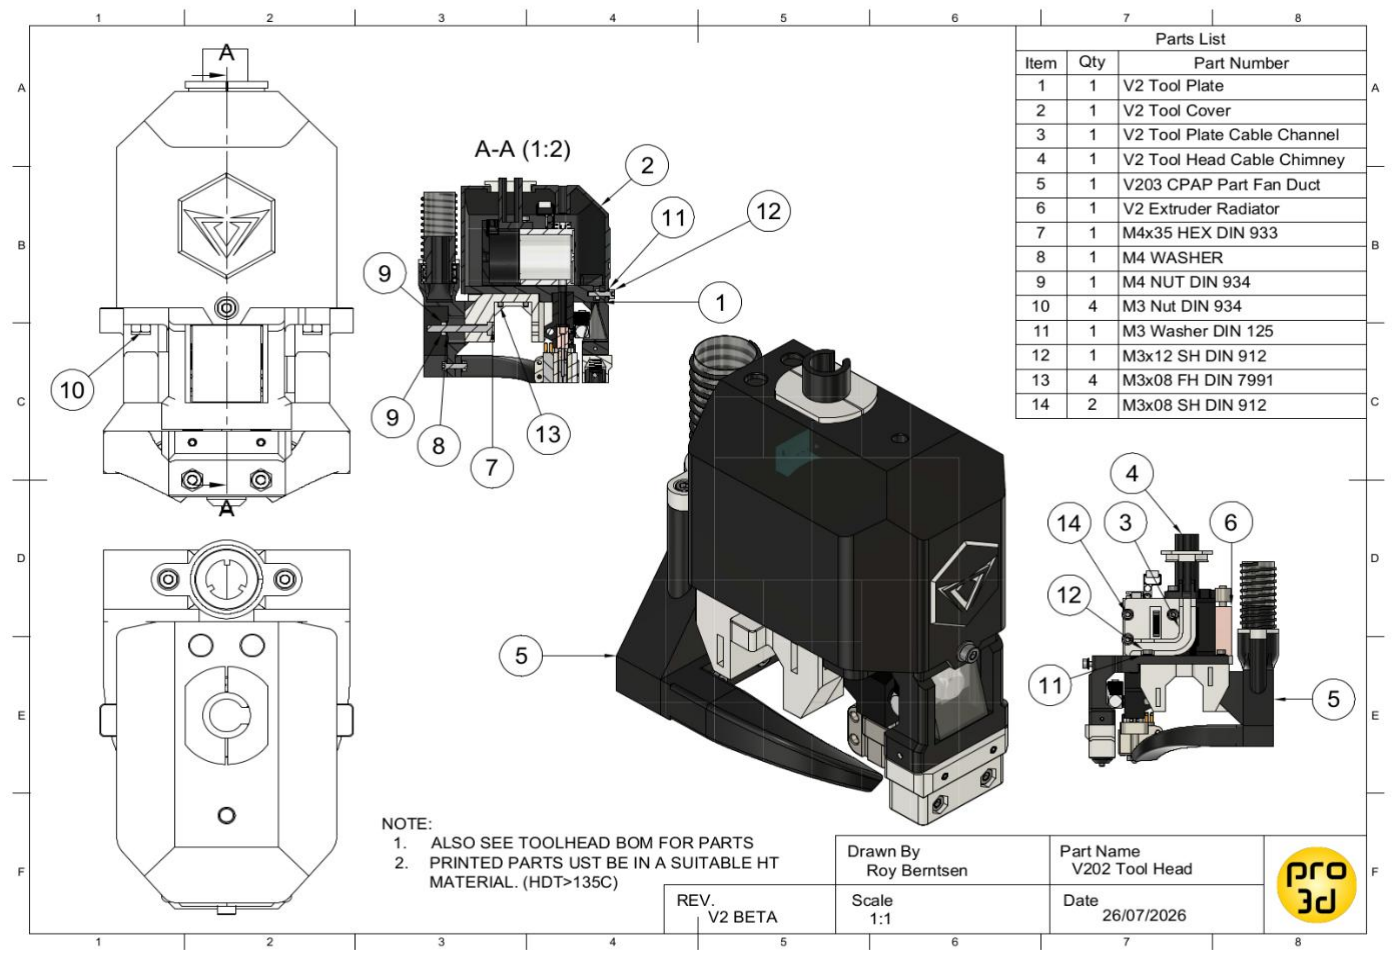
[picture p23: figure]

BETA PRELEASE | 2 of 2

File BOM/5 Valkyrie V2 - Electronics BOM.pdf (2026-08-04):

## VALKYRIE V2 - Electronics BOM

INDEX | Part name | Description | BOM Quantity
Support Links: | Cable 2:1 Heat Shrink Tube | 3mm | 1 | DEV TEAM
Buy Me a Coffee (https://ko-fi.com/pro3d) | Cable 2:1 Heat Shrink Tube | 4mm | 1 | Roy Berntsen
By Patreon (https://www.patreon.com/pro3d) | Cable 2:1 Heat Shrink Tube | 8mm | 1 | Mark Bridgewater
By PayPal (https://www.paypal.com/donate/?hosted_button_id=LZ7RAQGSE4SS8) | Cable Black | AWG 20 | 2
| Cable Black | AWG 24 | 5
| Cable Black | AWG 18 | 2
| Cable Black | AWG 14 | 2
| Cable Blue | AWG 20 | 2
| Cable Blue | AWG 24 | 2
| Cable Connector JST PH 2-Pin | LLL Buffer | 2
YouTube (https://www.youtube.com/@PRO3DESIGN) | Cable Connector JST PH 4-Pin | ROBO Fan | 1
| Cable Connector JST PH 6-Pin | Extruder motor | 1
| Cable Connector JST XH 3-Pin | LLL Buffer | 1
| Cable Connector JST XH 4-Pin | LLL Buffer | 1
| Cable Green | AWG 20 | 2
| Cable Green | AWG 24 | 2
| Cable mains PVC Brown | 1.5mm^2 | 3
| Cable mains PVC green/yellow | 1.5mm^2 | 3
| Cable mains PVC RED | 1.5mm^2 | 3
| Cable PET Braid sleeve | Cable Loom | 5
| Cable Red | AWG 18 | 2
| Cable Red | AWG 20 | 2
| Cable Red | AWG 24 | 5
| Cable Red | AWG 14 | 2
| Cable White | AWG 16 | 5
| Cable White | AWG 24 | 5
| Duet 3 6HC | Motherboard | 1
| DC 5.5x2.1mm Power Jack 1M 22AWG | Esp32 Shield | 1
| DIN Rail + terminal block kit UK2.5 | | 1
| Fan 4010 24V | MB/Robo Fan | 2
| Fan 6025 12V | Drybox | 1
| Grommets 12 mm | | 6
| GX20 flange mount & Plug 10pin | | 2
| GX20 flange mount & Plug 6pin | | 1
| HDC-HE-10core HD connector female | Bed connections | 1
| HDC-HE-10core HD connector male | Bed connections | 1
| HDC-HE-6core HD connector female | | 2
| HDC-HE-6core HD connector male | | 2
| LED Lighting - 24v led strip 5M | Chamber | 1
| M3 Washer DIN 125 | | 9
| M3x08 SH DIN 912 | | 6
| M3x10 SH DIN 912 | | 3
| M4 NUT DIN 934 | | 6
| M4 WASHER | | 13
| M4x14 SH DIN 912 | | 7
| M5 Nut DIN 934 | | 3
| M5 Nut Hammer Nut | | 16
| M5 WASHER DIN 125 | | 17
| M5x10 BH ISO 7380 | | 19
| Power Fuse holder 15A + 10A fuse | Power Main | 1
| Power Rocker switch AC 15A | Power Main | 1
| Power IEC extension lead | Power Drybox | 1
| Power Switch | Power Main | 1
| PSU 12V DC 75W meanwell | Power 12V | 1
| PSU 24V DC 350W meanwell | Power 24V | 1
| Resistor 10K | ROBO Fan | 1
| Resistor 4.7K | CPAP Temp | 1
| Solid State Relay | PWM Heaters | 3
| V2 Duet MB Buddy_1x | Print | 1
| V2 GX20 Buddy_1x | Print | 1
| V2 GX20 Cover_1x | Print | 1
| V2 HDC Buddy_1x | Print | 1
| V2 HDC Cover 10P_1x | Print | 1
| V2 HDC Cover 6P_2x | Print | 2
| V2 Plate_2x - Aluminium for DIN/SSR | 180x150x3mm | 2
| V2 PSU LRS-240 Buddy_1x | Print | 1
| V2 PSU LRS-75 Buddy_1x | Print | 1
BETA PRELEASE | 1 of 1

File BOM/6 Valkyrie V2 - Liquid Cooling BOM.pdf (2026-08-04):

## VALKYRIE V2 - LC BOM

INDEX | Part name | Description

BOM
Quantity
Support Links: | LC - 1/4" Barb - 4mm | 6 | DEV TEAM
Buy Me a Coffee (https://ko-fi.com/pro3d) | LC - Flowmeter | 1 | Roy Berntsen
By Patreon (https://www.patreon.com/pro3d) | LC - Pump P67D 12VDC | 1 | Mark Bridgewater
By PayPal (https://www.paypal.com/donate/?hosted_button_id=LZ7RAQGSE4SS8) | LC - Radiator 120mm | 1
| LC - Radiator Fan - 120mm | 1
| LC - Tubing 4x6mm IDxOD | 5
| M5 Nut Hammer Nut | 2
| M5x10 BH ISO 7380 | 2
| V2 Pump Bracket | 1
YouTube (https://www.youtube.com/@PRO3DESIGN) | V2 Radiator Bracket | 1

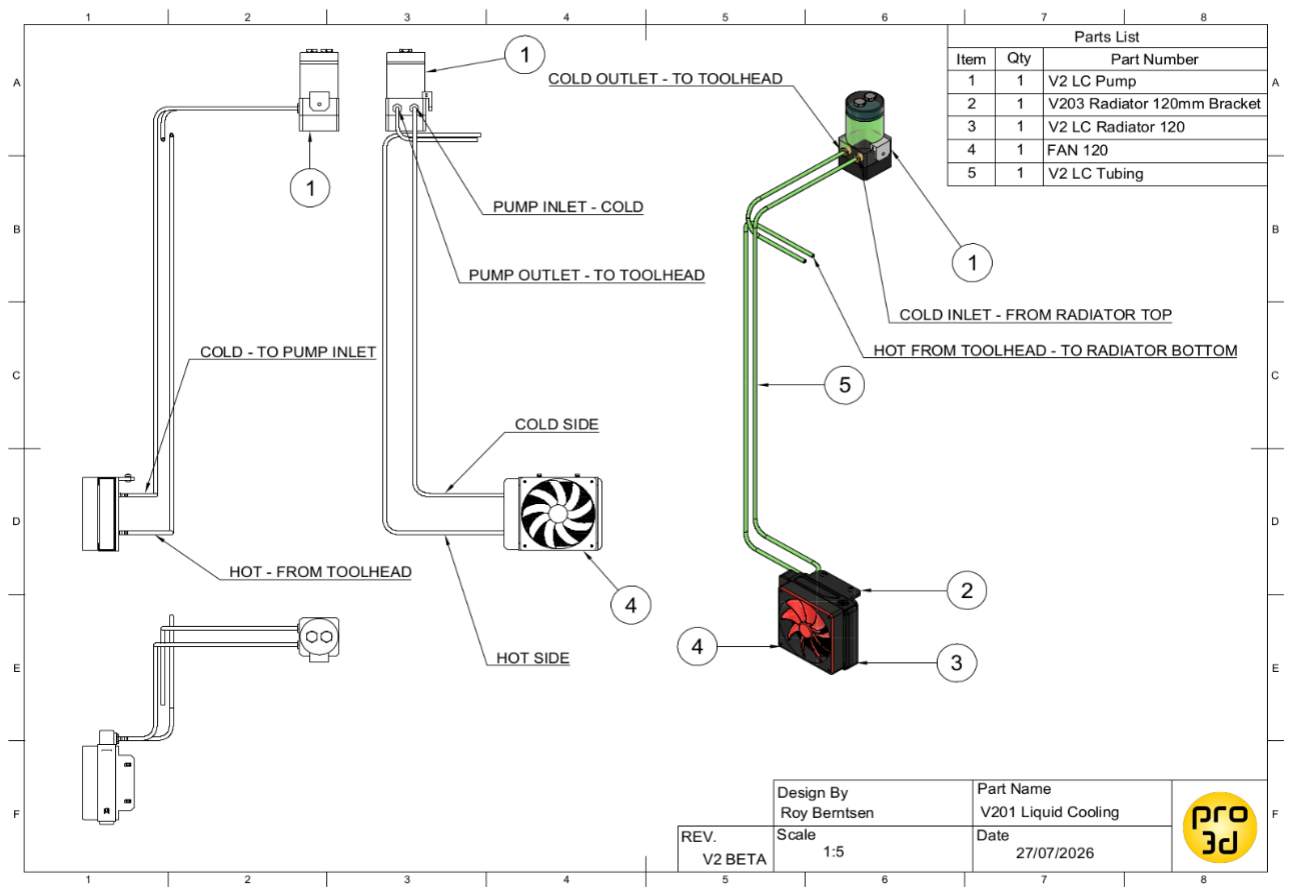
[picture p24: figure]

V2 BETA | 1 of 1

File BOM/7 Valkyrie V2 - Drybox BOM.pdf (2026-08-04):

## VALKYRIE V2 - DRYBOX BOM

INDEX | Part name | Description

BOM
Quantity
Support Links: | 05x08x1 Precision Shim | HW | 6 | DEV TEAM
Buy Me a Coffee (https://ko-fi.com/pro3d) | 05x10 D5 Shaft Collar DIN 705 | HW | 1 | Roy Berntsen
By Patreon (https://www.patreon.com/pro3d) | 05x16x5 Bearing 625ZZ | HW | 4 | Mark Bridgewater
By PayPal (https://www.paypal.com/donate/?hosted_button_id=LZ7RAQGSE4SS8) | 05x40 Bearing Shaft | HW | 3
| 07x10 Spring 0.4 WD | HW | 1
| DBX Drawer Slides 11435A14 | HW | 2
| DHT 22/BME 280 temp/humid sensor | Electronics | 1
| ESP32 + Expansion Board | Electronics | 1
| Fan Drybox Heater Fan 12V 4Pin | Electronics | 1
| GX20 10pin | Electronics | 1
| Heater PTC 220V 300W | Electronics | 1
YouTube (https://www.youtube.com/@PRO3DESIGN) | IEC connector | Electronics | 1
| Load Cell 5kg | Electronics | 1
| Loadcell amplifier HX711 | Electronics | 1
| M3 Nut DIN 934 | HW | 5
| M3 Washer DIN 125 | HW | 10
| M3x08 BH ISO 7380 | HW | 5
| M3x10 SH DIN 912 ISO 4762 | HW | 5
| M4 NUT DIN 934 v3 | HW | 4
| M4 WASHER v1 | HW | 8
| M4x12 FH DIN 7991 v3 | HW | 4
| M4x14 SH DIN 912 v4 | HW | 2
| M4x25 ST DIN 7981 v2 | HW | 2
| M4x35 HEX DIN 933 v4 | HW | 2
| M4x55 D5 Shoulder Screw v1 | HW | 1
| M5 Nut DIN 934 | HW | 2
| M5 WASHER DIN 125 | HW | 2
| M5x10 BH ISO 7380 | HW | 1
| M5x25 BH DIN 7380 | HW | 2
| Thermal Fuse 95C (https://s.click.aliexpress.com/e/_c33Nzeup) | Buy | 1
| V2 dbx insulation FB_2x (https://s.click.aliexpress.com/e/_c3xzfLHX) | Buy | 2
| V2 dbx insulation side_2x | Buy | 2
| V2 dbx insulation TB_2x | Buy | 2
| V2 dbx Panel FB_2x | Buy | 2
| V2 dbx Panel Side_2x | Buy | 2
| V2 dbx Panel TB_2x | Buy | 2
| V2 Drybox Draw Bracket | | 4
| V2 Drybox Draw Bracket Spacer | | 4
| V2 Friction Pad | | 5
| V2 Loadcell Spacer | | 1
| V203 Carousel Bearing Plate | | 1
| V205 Carousel Inner Ring | | 1
| V205 Carousel Outer Ring | | 1
| V205 Carousel Spool Adapter 54mm | | 1
| V205 Carousel Unspool Ring | | 1
| V205 Drybox Connector Buddy | | 1
| V205 Drybox Desiccant container | | 2
| V205 Drybox Desiccant Lid | | 2
| V205 Drybox Handle | | 1
| V205 Drybox PTC Heater/Fan Buddy | | 1
| V205 ESP32 HX711 Buddy | | 1
| V205 ESP32 HX711 Cover | | 1
| V206 Drybox Draw Front Panel | ACM | 1
V2 BETA | 1 of 2

## VALKYRIE V2 - DRYBOX BOM

V2 BETA | 2 of 2

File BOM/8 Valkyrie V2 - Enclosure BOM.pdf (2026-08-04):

## VALKYRIE V2 - ENCLOSURE BOM

INDEX | Part name | Description

BOM
Quantity
Support Links: | 05x08x1 Precision Shim | 18 | DEV TEAM
Buy Me a Coffee (https://ko-fi.com/pro3d) | 05x16x5 Bearing 625ZZ | 17 | Roy Berntsen
By Patreon (https://www.patreon.com/pro3d) | 08x12x1 Precision Shim | 2 | Mark Bridgewater
By PayPal (https://www.paypal.com/donate/?hosted_button_id=LZ7RAQGSE4SS8) | 08x16x5 Bearing 688ZZ | 2
08x400 Doorlink Steel Rod | 1
15x15 AL Tube L: 230mm | 4
20x03 Magnet Keepers | 6
20x06 Magnet 10kg | 6
300x300x3mm - PC Sheet | 286x286x3 | 2
Buffer - LLL Plus Filament Buffer | 1
Chamber Fan | 92x92x38 120CFM | 1
YouTube (https://www.youtube.com/@PRO3DESIGN) | Chamber Heater | 750W PTC 220V | 1
GX20 flange mount & Plug 10pin | 1
GX20 flange mount & Plug 6pin | 1
M3 Nut DIN 934 | 20
M3 Washer DIN 125 | 21
M3x08 SH DIN 912 | 10
M3x10 SH DIN 912 | 19
M4 NUT DIN 934 | 6
M4 Nut Nylock DIN 985 | 15
M4 WASHER DIN 125 | 16
M4x12 FH DIN 7991 | 4
M4x16 D5 Shoulder Screw | 6
M4x25 FH DIN 7991 | 4
M4x35 HEX DIN 933 | 2
M4x50 FH DIN 7991 | 6
M5 Nut DIN 934 | 16
M5 Nut Hammer Nut | 54
M5 WASHER DIN 125 | 80
M5x10 BH ISO 7380 | 14
M5x40 HEX DIN 931 | 44
M5x55 HEX DIN 931 ISO 4014 | 17
V2 BETA | 1 of 2

## VALKYRIE V2 - ENCLOSURE BOM

V2 Base Plate_1x | MDF Base Plate 10 mm | 1
V2 Insulation Base | PIR 30mm | 1
V2 Insulation Door | PIR 30mm | 1
V2 Insulation Rear | PIR 30mm | 1
V2 Insulation Side A | PIR 30mm | 1
V2 Insulation Side B | PIR 30mm | 1
V2 Insulation Top | PIR 30mm | 1
V2 Panel Door Front | ACM | 1
V2 Panel Door Side | ACM | 2
V2 Panel Door Top | ACM | 1
V2 Panel Rear Lower | ACM | 1
V2 Panel Rear Upper | ACM | 1
V2 Panel Side A Lower | ACM | 1
V2 Panel Side A Upper | ACM | 1
V2 Panel Side B Lower | ACM | 1
V2 Panel Side B Upper | ACM | 1
V2 Panel Top | ACM | 1
V205 AB Motor Cover | Printed | 1
V205 AB Motor Cover Bracket | Printed | 2
V205 BackPack_1x | Printed | 1
V205 Cable Gland Nut_1x | Printed | 1
V205 Cable Gland Tube_1x | Printed | 1
V205 Door Arm Hand AB_4x | Printed | 4
V205 Door Arm Lower Elbow AB_2x | Printed | 2
V205 Door Arm Upper Elbow A_1x | Printed | 1
V205 Door Arm Upper Elbow B_1x | Printed | 1
V205 Door Magnet Bracket Lower_2x | Printed | 2
V205 Doorhinge Side Bracket A_1x | Printed | 1
V205 Doorhinge Side Bracket B_1x | Printed | 1
V205 Doorhinge Upper Bracket A_1x | Printed | 1
V205 Doorhinge Upper Bracket B_1x | Printed | 1
V205 Front Door Bracket A_1x | Printed | 1
V205 Front Door Bracket B_1x | Printed | 1
V205 Front Door Handle A_1x | Printed | 1
V205 Front Door Handle B_1x | Printed | 1
V205 Panel Spacer_6x | Printed | 6
V205 PTFE Gland | Printed | 1
V205 PTFE Gland Nut | Printed | 1
V205 Swivel Cap_1x | Printed | 1
V205 Swivel Gland_1x | Printed | 1
V205 Swivel Top_1x | Printed | 1
V205 Window Frame Inner_2x | Printed | 2
V205 Window Frame Outer_1x | Printed | 1
V2 BETA | 2 of 2

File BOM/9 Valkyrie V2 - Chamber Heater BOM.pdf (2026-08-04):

## VALKYRIE V2 - Chamber Heater BOM

INDEX | Part name | Description

BOM
Quantity
Support Links: | Fan 92x38 FAN 12V | 1 | DEV TEAM
Buy Me a Coffee (https://ko-fi.com/pro3d) | M3x10 SH DIN 912 | 2 | Roy Berntsen
By Patreon (https://www.patreon.com/pro3d) | M4 NUT DIN 934 | 4 | Mark Bridgewater
By PayPal (https://www.paypal.com/donate/?hosted_button_id=LZ7RAQGSE4SS8) | M4x14 SH DIN 912 | 8
| M5 Nut Hammer Nut | 4
| M5x10 BH ISO 7380 | 4
| Heater PTC 750W 220V | 1
V205 PTC Heater Buddy | Printed | 1
V205 PTC Heater Grill Guard | Printed | 1

YouTube (https://www.youtube.com/@PRO3DESIGN)

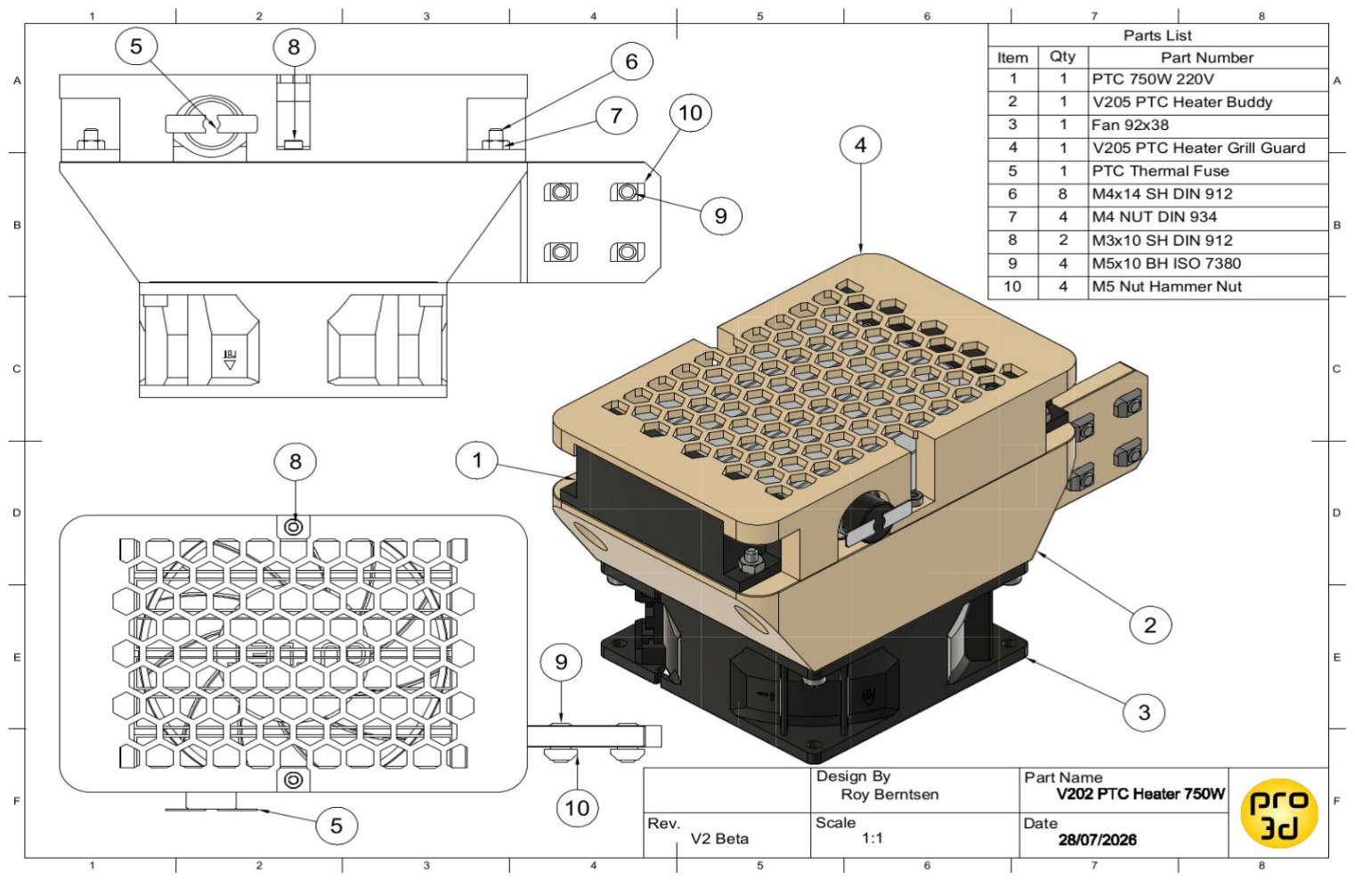
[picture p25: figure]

V2 BETA | 1 of 1

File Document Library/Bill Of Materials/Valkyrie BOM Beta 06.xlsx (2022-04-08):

PROJECT VALKYRIE
 | NB! WORK IN PROGRESS - BETA STAGE
 | Develompment Team Members
 | Mark Bridgewater - NZ
 | Chris Lombardi - US
 | Roy Berntsen - NO
 | Valkyrie | HT 3D Printer | Price exl VAT |  |  |  |  |  | $1835.46
System | Category | Part Type | Description | Cut Length mm | Total mm | BOM Quantity | Pack Price $ | Pack Order Quantity | Line Price $ | Order Parts Link | Supplier | DIN | ISO | Option | Note
Frame | Hardware | T-Slot 2020 | Z 2020 Rear Center | 339 | 339 | 1 | $7.26 | 1 | $8.00 | Color: 339 mm (https://s.click.aliexpress.com/e/_9xANon) | VenstPow |  |  |  | Precision Cut
Frame | Hardware | T-Slot 2020 | X 2020 Rear Top | 420 | 420 | 1 | $9.50 | 1 | $9.50 | Color: 420 mm (https://s.click.aliexpress.com/e/_9xANon) | VenstPow |  |  |  | Precision Cut
Frame | Hardware | T-Slot 2040 | X 2040 | 420 | 1680 | 4 | $10.54 | 4 | $42.16 | Color: 420 mm (https://s.click.aliexpress.com/e/_A2kG7t) | VenstPow |  |  |  | Precision Cut
Frame | Hardware | T-Slot 2040 | Y 2040 | 480 | 1920 | 4 | $11.12 | 4 | $44.48 | Color: 480 mm (https://s.click.aliexpress.com/e/_A2kG7t) | VenstPow |  |  |  | Precision Cut
Frame | Hardware | T-Slot 2040 | Z 2040 | 750 | 3000 | 4 | $14.70 | 4 | $58.80 | Color: 750 mm (https://s.click.aliexpress.com/e/_A2kG7t) | VenstPow |  |  |  | Precision Cut
Frame | Hardware | Bracket | 2028 L Bracket |  |  | 42 | $5.00 | 5 | $25.00 | 5x Color: 10pcs 2028 (https://s.click.aliexpress.com/e/_AqN7dv) | VenstPow |  |  | 8x Color: 2040-4 hole (https://s.click.aliexpress.com/e/_AlqdMr)
Kinematic | Motionparts | Linear Rails | MGN 12h - Z Axis | 350 |  | 3 | $15.60 | 3 | $46.80 | 3x GL: 350 - Color: MGN12 H (https://s.click.aliexpress.com/e/_AnfRXB) | VenstPow
Kinematic | Motionparts | Linear Rails | MGN 12h - Y Axis | 400 |  | 2 | $17.50 | 2 | $35.00 | 2x GL: 400 - Color: MGN12 H (https://s.click.aliexpress.com/e/_AnfRXB) | VenstPow
Kinematic | Motionparts | Linear Rails | MGN 9h - X Axis | 400 |  | 1 | $16.00 | 1 | $16.00 | 1x GL: 400 - Color: MGN9 H (https://s.click.aliexpress.com/e/_AnfRXB) | VenstPow
Frame | Hardware | Frame Bundle | 2040 Frame Kit - Ask for bundle price |  |  | 1 | $210.00 | 1 | $265.60 | Ask for Precision Cut Frame Bundle (https://s.click.aliexpress.com/e/_AAZ5RN) | VenstPow
Frame | Hardware | Tube | 20x20x18 Carbon Tube | 410 | 500 | 1 | $20.00 | 1 | $20.00 | 20X20X18MM 500MM (https://s.click.aliexpress.com/e/_AK9Uei) | YTWS
Bed | Hardware | Plate | Cast Aluminum 350x350x8mm | 350 |  | 1225 | $0.08 | 1225 | $98.00 | 1225 cm^2 (https://makersupplies.dk/en/aluminum-sheet/921-aluminum-sheet-8mm-cnc-milled-cast-aluminum-sheet-custom-cut.html) | MakerSupplies
Bed | Hardware | Print Surface | Removal Spring Steel Sheet | 310 |  | 1 | $40.00 | 1 | $40.00 | Size: 310x310mm (https://s.click.aliexpress.com/e/_AKIu5X) | Energetic
Kinematic | Hardware | Rod | 5x25mm Rod For Tension Forks | 25 |  | 5 | $1.20 | 1 | $1.20 | 1x Length: 25mm 8PC (https://s.click.aliexpress.com/e/_AM7dI0) | WanFang
Kinematic | Hardware | Rod | 5x40mm Rod For AB Idlers | 40 |  | 12 | $3.00 | 3 | $9.00 | 3x Length: 40mm 5PC (https://s.click.aliexpress.com/e/_AM7dI0) | WanFang
Bed | Hardware | Rod | 5x50mm Rod For Ball Joint | 50 |  | 6 | $3.00 | 2 | $6.00 | 2x Length: 50mm 4PC (https://s.click.aliexpress.com/e/_AM7dI0) | WanFang
Bed | Hardware | Ball Joint | Precision Ball 10mm M4 |  |  | 3 | $3.00 | 1 | $3.00 | 1x Size: 10pc (https://s.click.aliexpress.com/e/_ArYZR8) | KingRoon
Bed | Hardware | Magnet | Neodium Magnet | 30 |  | 3 | $2.50 | 2 | $5.00 | 2x 30x10x5mm-2pcs (https://s.click.aliexpress.com/e/_A2lsvE) | HongKai
Kinematic | Hardware | Bearings | 625 2ZZ |  |  | 6 | $7.50 | 1 | $7.50 | 10pcs 625ZZ 5x16x5mm (https://s.click.aliexpress.com/e/_AZ42Hh) | VenstPow
Frame | Fasteners | Nut | M3 Nut |  |  | 21 | $1.00 | 1 | $1.00 | 1x Size: M3 50PCS (https://s.click.aliexpress.com/e/_AB2MMx) | WanFang | 934 | 4032
Frame | Fasteners | Nut | M3 Nut Hammer Nut |  |  | 34 | $3.00 | 1 | $3.00 | 1x 50PCS Size: 20-m3 (https://s.click.aliexpress.com/e/_A3vamf) | WanFang
Frame | Fasteners | Screw | M3x08 BH |  |  | 24 | $1.00 | 1 | $1.00 | 1x Size: M3 50PCS - 8mm - 304 SS (https://s.click.aliexpress.com/e/_A3cUtH) | WanFang |  | 7380
Frame | Fasteners | Screw | M3x08 SH |  |  | 34 | $1.00 | 1 | $1.00 | 1x Size: M3 50PCS - 8mm - 304 SS (https://s.click.aliexpress.com/e/_9JOB4f) | WanFang | 912
Frame | Fasteners | Screw | M3x10 BH |  |  | 33 | $1.00 | 1 | $1.00 | 1x Size: M3 50PCS - 10mm - 304 SS (https://s.click.aliexpress.com/e/_A2YDOx) | WanFang |  | 7380
Frame | Fasteners | Screw | M3x16 BH |  |  | 8 | $2.00 | 1 | $2.00 | 1x Size: M3 50PCS - 16mm - 304 SS (https://s.click.aliexpress.com/e/_A2YDOx) | WanFang |  | 7380
Frame | Fasteners | Screw | M4 D5 L55 Shoulder Screw |  |  | 3 | $4.00 | 3 | $12.00 | 3x Size: M4-D5mm (https://s.click.aliexpress.com/e/_9x0mWr) | YFS
Frame | Fasteners | Nut | M4 Nut |  |  | 6 | $1.50 | 1 | $1.50 | Size: M4 50PCS (https://s.click.aliexpress.com/e/_AtAfsX) | WanFang | 934 | 4032
Frame | Fasteners | Nut | M4 Nut Lock Nut |  |  | 3 | $1.50 | 1 | $1.50 | Size: M4 50PCS - Color SS (https://s.click.aliexpress.com/e/_AkJ18P) | WanFang | 985 | 10511
Frame | Fasteners | Washer | M4 WASHER |  |  | 3 | $1.00 | 1 | $1.00 | 1x M4 50pcs (https://s.click.aliexpress.com/e/_97Edtp) | WanFang | 125 | 7089
Frame | Fasteners | Screw | M4x16 CS |  |  | 3 | $2.00 | 1 | $2.00 | 1x Size: M4 20PCS - 16mm - 304 SS (https://s.click.aliexpress.com/e/_9RUjsB) | WanFang |  | 7991
Frame | Fasteners | Screw | M4x20 CS |  |  | 3 | $2.00 | 1 | $2.00 | 1x Size: M4 20PCS - 20mm - 304 SS (https://s.click.aliexpress.com/e/_ASPnXl) | WanFang |  | 7991
Frame | Fasteners | Nut | M5 Nut |  |  | 4 | $2.00 | 1 | $2.00 | 1x Size: M5 50PCS (https://s.click.aliexpress.com/e/_AMyL9p) | WanFang | 934 | 4032
Frame | Fasteners | Nut | M5 Nut Hammer Nut |  |  | 30 | $11.00 | 1 | $11.00 | 1x M5 100 PCS (https://s.click.aliexpress.com/e/_A28QM3) | WanFang
Frame | Fasteners | Nut | M5 Nut Locknut |  |  | 5 | $2.81 | 1 | $2.81 | 1x M5 50 PCS - SS (https://s.click.aliexpress.com/e/_ACjUAP) | WanFang | 985 | 10511
Frame | Fasteners | Nut | M5 Nut T-Nut |  |  | 84 | $13.50 | 1 | $13.50 | 1x M5 100PCS (https://s.click.aliexpress.com/e/_9iXP6T) | WanFang
Frame | Fasteners | Washer | M5 WASHER |  |  | 89 | $1.28 | 2 | $2.56 | 2x M5 50PCS (https://s.click.aliexpress.com/e/_9vb6PD) | WanFang | 125 | 7089
Frame | Fasteners | Screw | M5x10 BH |  |  | 111 | $2.69 | 12 | $32.28 | 12x 10PCS Size: M5 - 10mm - SS (https://s.click.aliexpress.com/e/_AkraqJ) | WanFang |  | 7380
Frame | Fasteners | Screw | M5x20 BH |  |  | 7 | $8.00 | 1 | $8.00 | 1x 10PCS Size: M5 - 20mm - SS (https://s.click.aliexpress.com/e/_9zqQrh) | WanFang |  | 7380
Frame | Fasteners | Bolt | M5x30 HEX |  |  | 5 | $2.57 | 1 | $2.57 | 1x 10 PCS Size: M5 - 30mm (https://s.click.aliexpress.com/e/_980mef) | WanFang | 933 | 4017
Frame | Fasteners | Shim | M5x6.5x1 Precision Shim |  |  | 33 | $16.00 | 1 | $16.00 | 1x 200PCS Size: 6.5x5x1mm (https://www.aliexpress.com/item/32874190317.html?spm=2114.12010612.8148356.2.6b2842c5nKhsGR) | BulkMan
Enclosure | Fasteners | Washer | Cup Washer for Outer Panels |  |  |  | $8.00 | 1 | $8.00 | 1x 20PCS cup head washer (https://s.click.aliexpress.com/e/_AZbcPt) | WanFang
Frame | Fasteners | Washer | M3 WASHER |  |  |  | $0.74 | 1 | $0.74 | 1x: M3 50pcs (https://id.aliexpress.com/item/1005003078979017.html) | WanFang | 125
AC/DC | Electronics | Safety relay | Hongfa 24V ac DPDT Interface Relay |  |  | 1 | $12.00 | 1 | $12.00 | item nr. 137-2111 | RS Components
AC/DC | Electronics | Controller Board | BTT Octopus V1.1 |  |  | 1 | $70.00 | 0 | $0.00 | 1x TMC2209 x8 (https://s.click.aliexpress.com/e/_A6fsH6) | BigTreeTech
AC/DC | Electronics | Controller Board | Big Dipper D3 Mini |  |  | 1 | $71.00 | 1 | $71.00 | 1x Big Dipper (https://s.click.aliexpress.com/e/_9uMnUG) | Fysetc
AC/DC | Electronics | PSU | Power Supply Unit |  |  | 1 | $23.00 | 1 | $23.00 | 24V10A 240W (https://s.click.aliexpress.com/e/_9v6vDi) | Vusum
AC/DC | Electronics | Switch | Power Switch |  |  | 1 | $7.50 | 1 | $7.50 | 1x Power switch (https://s.click.aliexpress.com/e/_AX4lXw) | TriangleLab
AC/DC | Electronics | Heater | 110/220V 750W Heating Pad | 310 |  | 1 | $28.00 | 1 | $28.00 | 1x Select Color: 220V/110V (https://s.click.aliexpress.com/e/_AWE3wb) | IdeaFormer |  |  |  | Note
AC/DC | Electronics | Switch | Solid State Relay |  |  | 3 | $26.00 | 3 | $78.00 | Genuine Omron Solid State Relay (https://s.click.aliexpress.com/e/_9uL5H7) | Mellow |  |  | Size: SSR 25DA (https://s.click.aliexpress.com/e/_ACLUdT)
ToolHead | Electronics | Probe | Z Probe - Bl Touch Type |  |  | 1 | $20.00 | 1 | $20.00 | 3D Touch (https://s.click.aliexpress.com/e/_97LgT3) | TriangleLab
ToolHead | Electronics | Accelerometer | LIS3DSH Accelerometer |  |  | 1 | $2.00 | 1 | $2.00 | 1x LIS3DSH Accelerometer (https://s.click.aliexpress.com/e/_APFI3d)
ToolHead | Electronics | Accelerometer | ADXL345 Accelerometer |  |  | 1 | $3.00 | 0 | $0.00 | 1x ADXL345 Accelerometer (https://s.click.aliexpress.com/e/_AeVYOF)
AC/DC | Electronics | Fuse | Thermal Fuse for Silicone Heating Pad |  |  | 1 | $3.00 | 1 | $3.00 | 250V 15A 135 deg Fuse (https://s.click.aliexpress.com/e/_ACLr6b) | Weidly
ToolHead | Extruder | Hotend | Dragon LC Hotend |  |  | 1 | $85.00 | 1 | $85.00 | DLC Standard Flow (https://s.click.aliexpress.com/e/_9wXMi0) | TriangleLab
ToolHead | Extruder | Hotend | Dragon AC Hotend |  |  | 1 | $72.71 | 0 | $0.00 | Color: Dragon-Standard flow (https://s.click.aliexpress.com/e/_A36iOH) | TriangleLab
ToolHead | Extruder | Extruder | Orbiter V2 |  |  | 1 | $65.00 | 0 | $0.00 | Orbiter Extruder V2 (https://s.click.aliexpress.com/e/_A9K7Gg) | TriangleLab
ToolHead | Extruder | Extruder | Matrix LC Lite |  |  | 1 | $100.00 | 0 | $0.00 | 24V Matrix-LC (https://s.click.aliexpress.com/e/_9iVnZe) | TriangleLab
ToolHead | Extruder | Extruder | Bontech LGX Lite |  |  | 1 | $70.00 | 1 | $70.00 | LGX® Lite + LDO NEMA 14 (https://www.bondtech.se/product/lgx-lite-extruder-custom/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) | Bondtech
Kinematic | Motionparts | Belt | Timing Belt 2GT 9mm 135C | 1000 | 8000 | 8 | $59.00 | 1 | $59.00 | 1x 8M Heat Resistant - 9mm (https://s.click.aliexpress.com/e/_ABtzv6) | TriangleLab
Kinematic | Motionparts | Idler | Idlers Smooth 11mm |  |  | 10 | $4.10 | 10 | $41.00 | 10x W 11mm without t (https://s.click.aliexpress.com/e/_9gG5gi) | Mellow
Kinematic | Motionparts | Idler | Idlers Toothed 11mm |  |  | 5 | $6.00 | 5 | $30.00 | 5x W 11mm with t (https://s.click.aliexpress.com/e/_9gG5gi) | Mellow
Kinematic | Motionparts | Pulley | Pulley 11mm 2GT |  |  | 5 | $4.00 | 5 | $20.00 | 5x For 9mm (https://s.click.aliexpress.com/e/_A6Q066) | Mellow
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

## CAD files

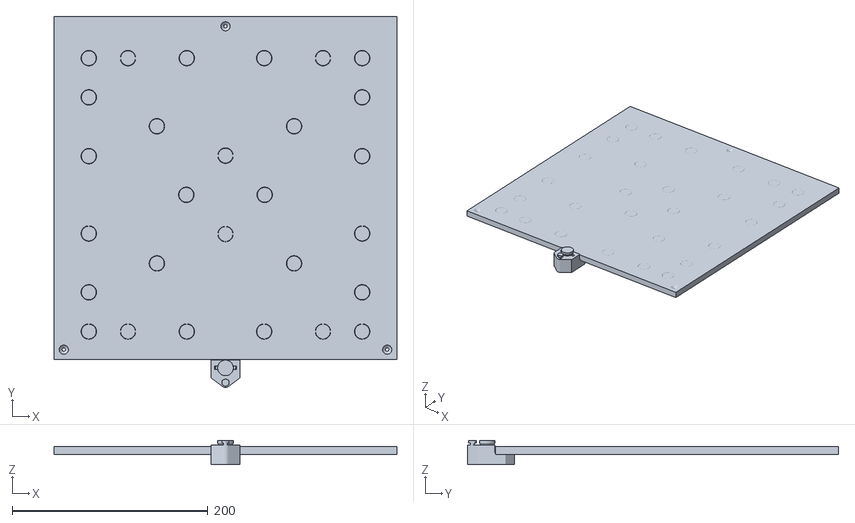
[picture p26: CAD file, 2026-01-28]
docs/images/Valkyrie bed logos/V2 Build plate slicer version.stl
350.0 x 378.6 x 25.0

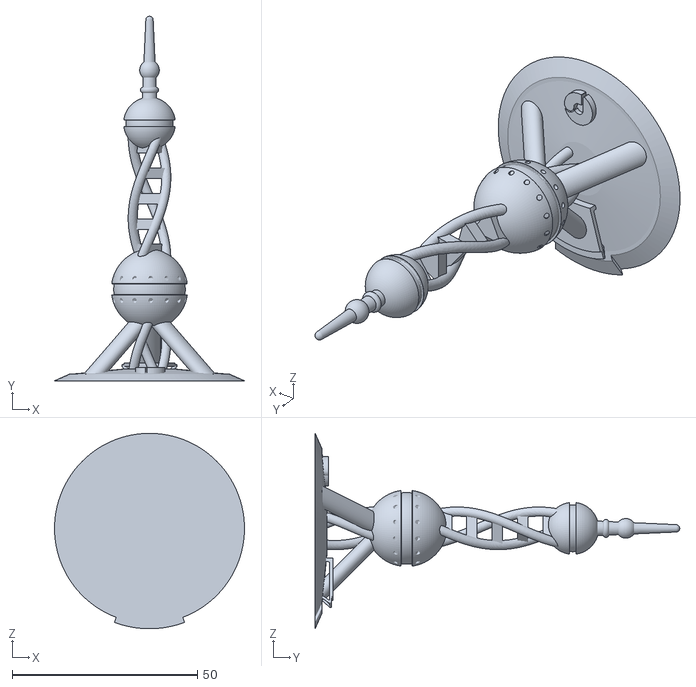
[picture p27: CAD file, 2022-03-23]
Part File Library/Calibration Files/PolyPearl_Tower.STL
51.2 x 98.3 x 52.7

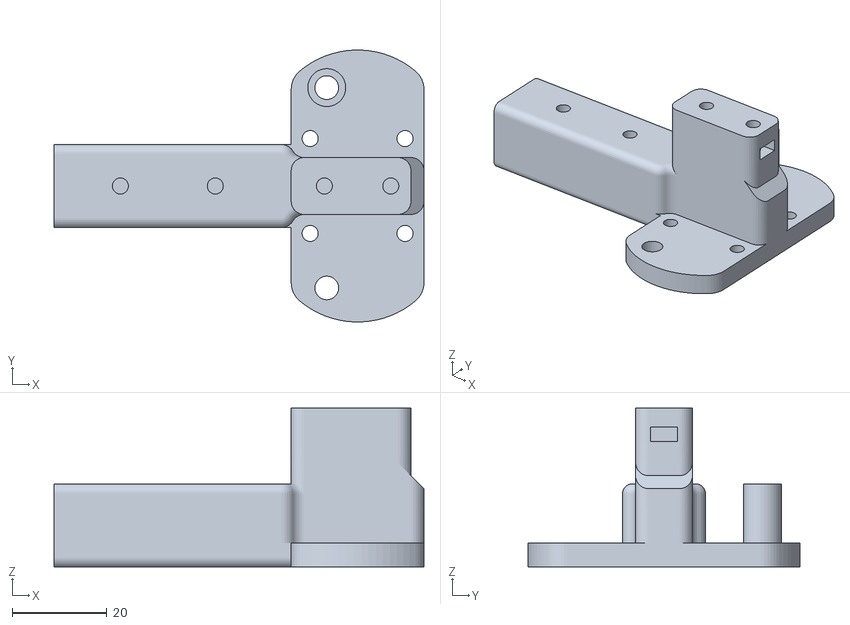
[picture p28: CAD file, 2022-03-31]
Part File Library/Print Files/3030 Print Files/printed/3030 Y Carrier B_1x.stl
78.0 x 57.3 x 33.5

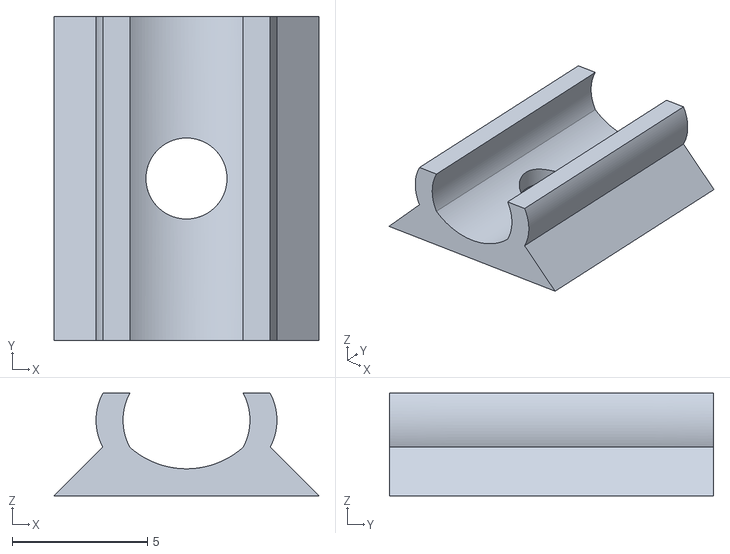
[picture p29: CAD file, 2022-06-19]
Part File Library/Print Files/Option Parts/V Slot Cable Cover_10x_SN_BN.stl
9.80 x 12.0 x 3.80

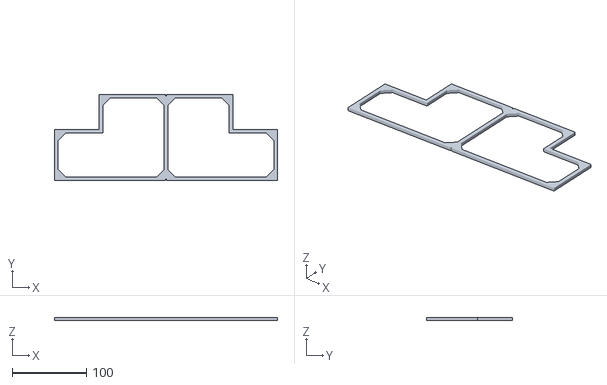
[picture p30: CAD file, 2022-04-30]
Part File Library/Print Files/Templates/Panel Rear Cut Template.stl
300.0 x 116.0 x 4.00

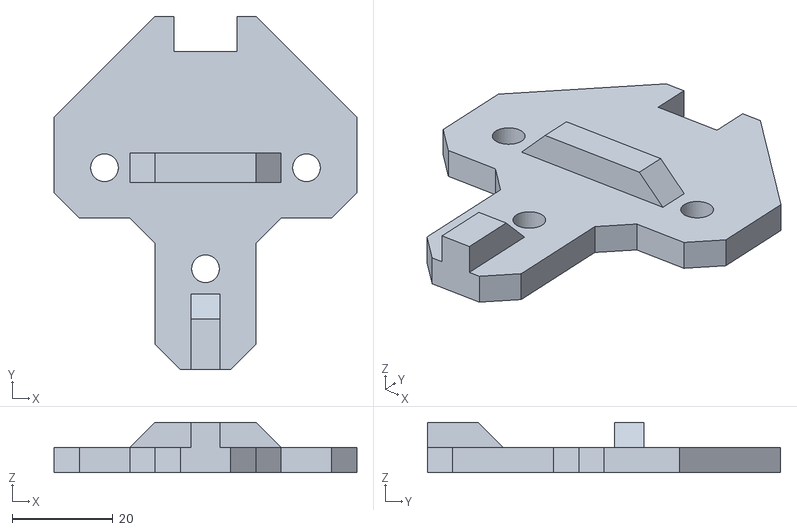
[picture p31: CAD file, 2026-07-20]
Part-Files/0 FRAME PARTS/V205 Z Support Bracket_1x.stl
60.0 x 70.0 x 10.0

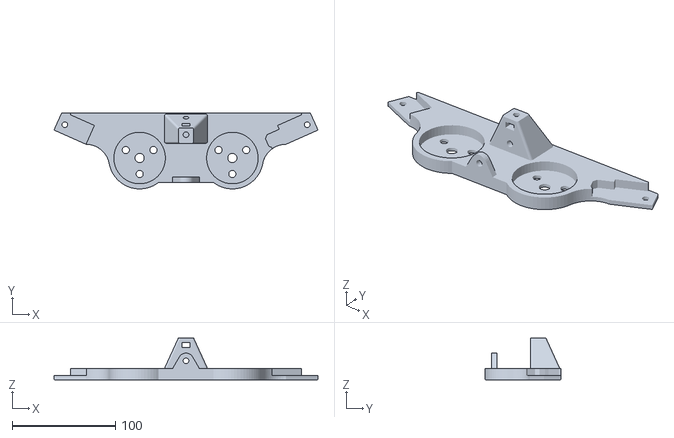
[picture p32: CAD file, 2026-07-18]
Part-Files/1 AB SYSTEM PARTS/V205 AB Motor Brace_1x.stl
256.1 x 73.5 x 40.5

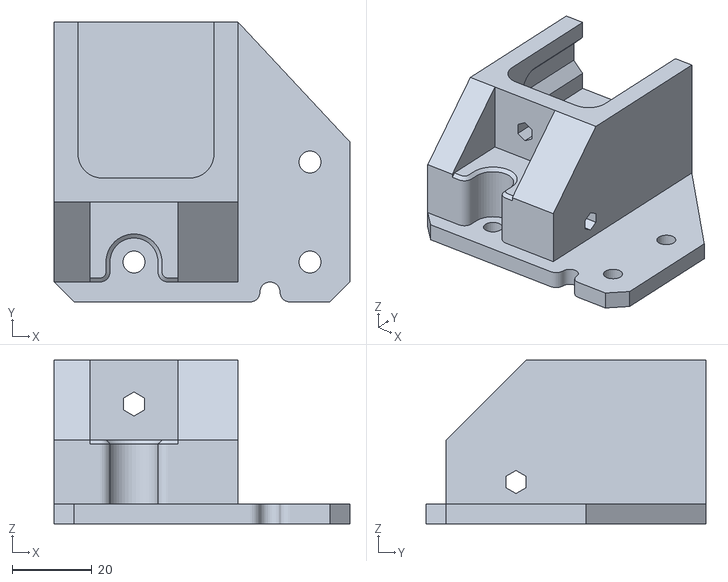
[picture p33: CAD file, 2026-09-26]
Part-Files/2 Z SYSTEM PARTS/V205 Z Idler Tower B_1x.stl
74.0 x 70.0 x 41.0

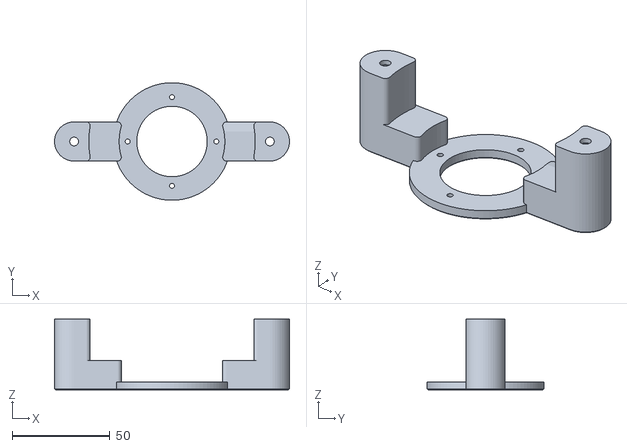
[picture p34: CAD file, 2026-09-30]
Part-Files/3 TOOLHEAD PARTS/V205 CPAP ROBO Fan Bracket_1x.stl
120.0 x 60.0 x 36.0

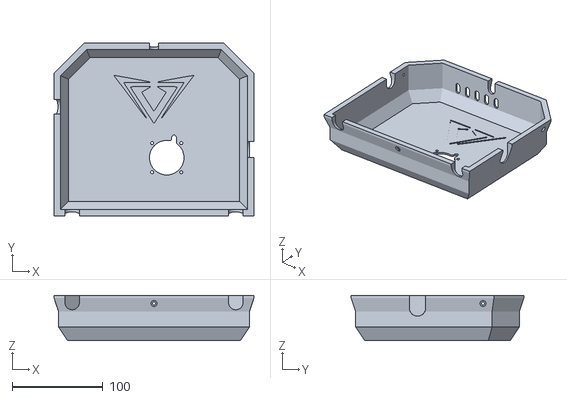
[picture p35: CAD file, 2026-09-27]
Part-Files/4 ELECTRONIC PARTS/V205 Duet Cover_1x.stl
220.0 x 190.0 x 50.0

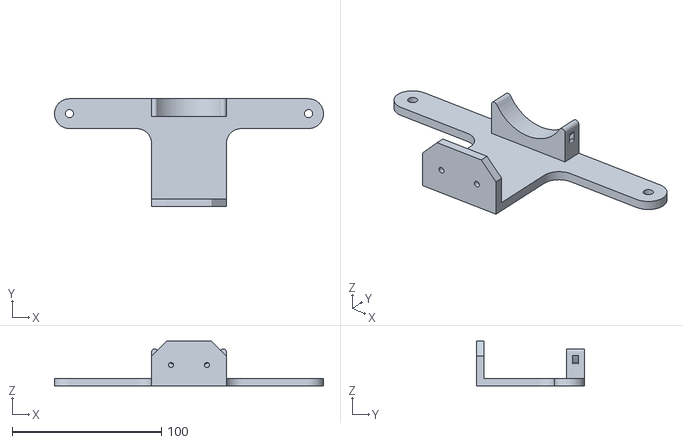
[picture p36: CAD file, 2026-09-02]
Part-Files/5 LC SYSTEM PARTS/V205 LC Pump Buddy_1x.stl
180.0 x 72.0 x 30.0

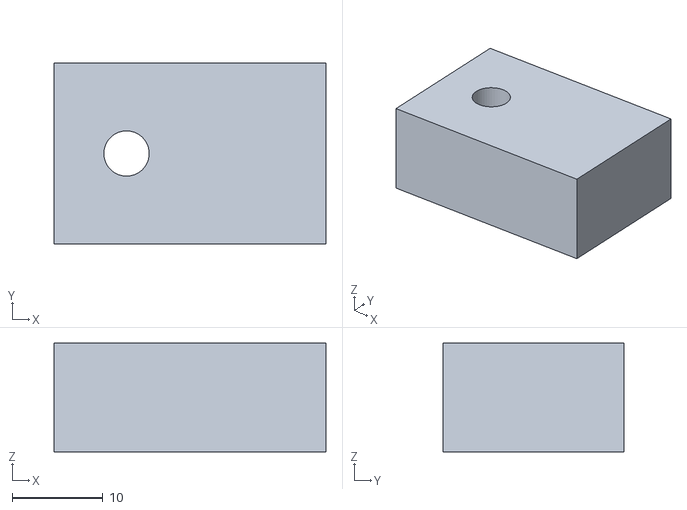
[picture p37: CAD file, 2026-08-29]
Part-Files/6 DRYBOX PARTS/V205 Drybox Bracket Spacer_4x.stl
30.0 x 20.0 x 12.0

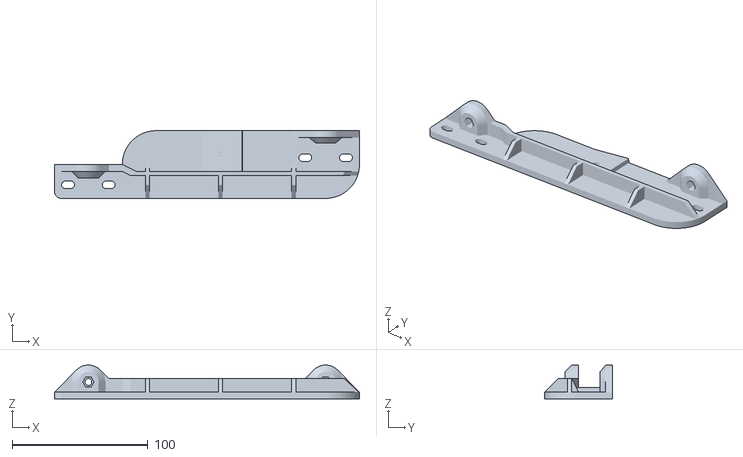
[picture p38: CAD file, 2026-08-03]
Part-Files/7 ENCLOSURE PARTS/V2 DOOR PARTS/V205 Door Bracket A_1x.stl
225.0 x 50.0 x 25.0

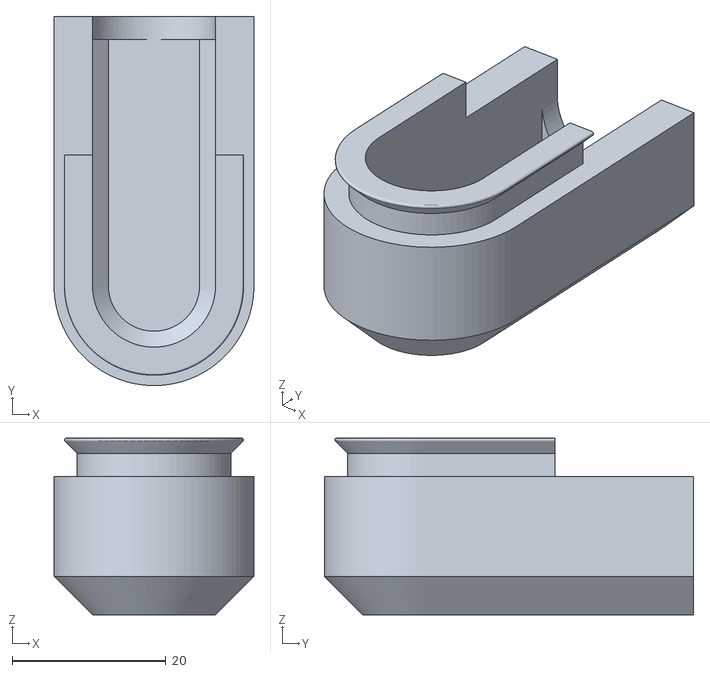
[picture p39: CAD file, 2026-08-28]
Part-Files/7 ENCLOSURE PARTS/V205 Panel Rear Lower Trunking Cover_3x.stl
26.0 x 48.0 x 23.0

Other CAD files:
Part-Files/8 TOOLS/MGN 09 2020 Alignment Buddy_2x.stl
Source-Files/V2 Mothend.step
V2 BETA/PART FILES/AB PARTS/V2 AB Y Carrier A2_1x.stl
Part File Library/Calibration Files/100^3 cube.stl
Part File Library/Calibration Files/100^3 cylinder.stl
Part File Library/Calibration Files/303020 Calibration Cube.stl
Part File Library/Calibration Files/Stringing_Test.stl
Part File Library/Calibration Files/Voron_Design_Cube_v7.stl
Part File Library/Calibration Files/ringing_tower.stl
Part File Library/Calibration Files/xyzCalibration_cube.stl
Part File Library/Calibration Files/z-wobble-test-square.stl
Part File Library/Calibration Files/z-wobble-test.stl
Part File Library/Print Files/3030 Print Files/printed/3030 A Idler Bracket Front_1x.stl
Part File Library/Print Files/3030 Print Files/printed/3030 A Idler Bracket Rear_1x.stl
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

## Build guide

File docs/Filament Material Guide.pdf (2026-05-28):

## Filament Material Guide

High-Performance Filaments with HDT (2026 Reference)
Note: The values maybe different depending on the brands - Check
C | C | C | C | C | Hr | E

Filament Name

Build
Sheet

Cooling
Fan
| | Speed | Tg | Nozzle
| | | | Temp | Bed
| | | | | Temp | Chamber
| | | | | | Temp | Drying
| | | | | | | Temp | Drying
Time HDT HDT-A
| | | | | | | | | | | Bending
| | | | | | | | | | | Modulus
| | | | | | | | | | | MPa
ABS | PEI/Glass | Low 105 | 225 | 110 | 60 | 75 | 4 | 95 | 100 | 2300
ASA | PEI/Glass | Low 105 | 245 | 110 | 60 | 80 | 3 | 95 | 100 | 2000
CPE | PEI | Medium | 90 | 250 | 80 | 20 | 60 | 3 | 70 | 75 | 1900
HIPS | PEI | 0 100 | 225 | 100 | 50 | - | - | 80 | 80 | 1600
PA 6 | G10/FR4 | Low 105 | 265 | 110 | 70 | 90 | 4 | 140 | 180 | 2050
PA ePA CF | G10/FR4 | Low | 60 | 260 | 90 | 60 | 80 10 | 110 | 180 | 6500
PA12 CF | G10/FR4 | Low | 60 | 260 | 80 | 55 | 80 | 8 | 135 | 180 | 3000
PA12 GF | G10/FR4 | Low | 60 | 260 | 90 | 50 | 80 | 6 | 135 | 180 | 2900
PA6 GF | G10/FR4 | Low | 70 | 260 | 90 | 60 | 80 10 | 140 | 180 | 4800
PC | PEI | 0 147 | 285 | 115 | 60 | 120 | 4 | 135 | 135 | 2200
PC + ABS | Low 137 | 275 | 110 | 80 | 110 | 4 | 126 | 128 | 2370
PC + ASA | Low 126 | 265 | 110 | 90 | 110 | 4 | 126 | 128 | 2370
PC BambuLab | PEI | Low 145 | 260 | 90 | 60 | 80 | 8 | 112 | 114 | 2300
PC Blend CF Prusa PEI | Low 113 | 285 | 110 | 60 | 80 | 5 | 114 | 130 | 4200
PC BLEND LCF* | Low 158 | 280 | 100 | 90 | 80 | 6 | 185 | 185 | 9800
PC CF/GF | Low 143 | 280 | 110 | 100 | 80 | 5 | 135 | 140 | 6000
PC PBT CF | Low 140 | 260 | 100 | 100 | 80 | 5 | 110 | 110 | 6200
PC Polymax | PEI | Low 113 | 250 | 90 | 70 | 75 12 | 114 | 116 | 2040
PEEK | CF/PEI | Low 143 | 390 | 135 | 100 | 120 | 4 | 140 | 280 | 3700
PEKK | CF/PEI | Low 165 | 370 | 130 | 150 | 120 | 4 | 182 | 300 | 2900
PEKK CF | CF/PEI | Low 165 | 380 | 120 | 140 | 120 | 6 | 180 | 300 | 9850
PET CF | PEI | Low | 70 | 260 | 70 | 55 | 80 10 | 112 | 225 | 6500
PETG | PEI | Medium | 80 | 245 | 70 | 35 | 65 | 3 | 70 | 70 | 1600
PLA | PEI | High | 85 | 210 | 23 | 25 | 65 | 3 | 60 | 100 | 3500
PPA CF | PEI | Low | 90 | 300 | 90 | 60 | 100 | 8 | 227 | 250 | 9800
PPS | PEI | 0 283 | 340 | 120 | 70 | 110 | 4 | 90 | 250 | 2540
PPS CF | PEI | 0 100 | 320 | 110 | 80 | 100 10 | 264 | 280 | 7160
PPSU | PC/PEI | 0 230 | 400 | 140 | 100 | 120 | 4 | 190 | 210 | 2215
PSU | FR4 | 0 187 | 365 | 130 | 130 | 120 | 4 | 172 | 180 | 2050
PVDF | Low 170 | 265 | 105 | 100 | - | - | 158 | 160 | 2100
TPC FLEX | | Medium | 80 | 235 | 70 | 35 | 65 | 4 | 120 | 120 | 100
ULTEM 1010 | PC/PEI | 0 186 | 375 | 135 | 110 | 120 | 4 | 208 | 210 | 3000
ULTEM 9085 | 0 180 | 360 | 130 | 170 | 110 | 5 | 177 | 180 | 2200
*Add North
NOTE:
Abrasive Protection:
Glass Fiber (GF) and Carbon Fiber (CF) will destroy brass nozzles.
A hardened steel or tungsten carbide nozzle is mandatory
Thermal Treatment:
Semi-crystalline polymers like PPS-CF and PPA-CF often require annealing to reach their maximum rated HDT Active Drying:
These materials must be dried at 80°C–120°C for 8+ hours before printing to prevent structural defects Amorphous Materials (PC, ABS, ASA, PETG, ULTEM):
These materials generally do not benefit from annealing in terms of HDT.
Annealing is used here primarily to reduce internal stresses and prevent warping later on. Semi-Crystalline Materials (PLA, PPS, Nylon, PEEK):
Annealing is required to reach the high HDT values listed.
Without annealing, these parts will soften significantly at much lower temperatures.

## Filament Material Guide

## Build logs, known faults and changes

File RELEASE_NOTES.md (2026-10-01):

# Valkyrie V2.0.0-rc.1 - Release Candidate 1

Release date: October 2026

Valkyrie V2.0.0-rc.1 is the first release candidate for the V2 platform. It builds on the V2.0.0 beta releases with additional firmware safety monitoring, improved fault recovery, revised print-start heating behaviour, documentation cleanup, and release-structure improvements.

Recommended operating values are separated from verified prototype results. Verified values represent demonstrated results on the Valkyrie V2 reference machine and should not be interpreted as required operating settings for every build.

## Changes since V2.0.0-beta.2

### Firmware safety and fault recovery

- Added tachometer monitoring for the main chamber circulation fan, drybox fan, and water-cooling pump.
- The chamber heater is automatically shut down if chamber-fan RPM remains below the configured safety threshold for two consecutive daemon cycles.
- The drybox heater is automatically shut down if drybox-fan RPM remains below the configured safety threshold for two consecutive daemon cycles.
- Water-pump monitoring becomes active once the hotend exceeds 60 °C.
- A confirmed water-pump fault during a print automatically pauses the print and shuts down the hotend heater.
- Pump-fault resume handling verifies pump RPM before reheating, restores the saved hotend temperature, waits for the hotend to recover, performs a final pump check, and only then resumes the print.
- Stop and cancel handling clears stored water-pump fault and recovery state.
- Chamber and drybox fan monitoring retain independent firmware fault handling in addition to the machine's physical thermal protection.

### Print-start and thermal behaviour

- Added a minimum-chamber-temperature wait routine for print start.
- Bed and chamber heating can now begin before the hotend is heated, reducing unnecessary hotend dwell time during long chamber preheats.
- Hotend firmware temperature limit aligned with the 500 °C rated Valkyrie hotend configuration.

### Repository and documentation

- Firmware files are organised directly under `Firmware Files/sys`, `Firmware Files/macros`, and `Firmware Files/filaments`.
- Removed obsolete SD-card-folder references and stale backup/archive files from the public `sys` and `macros` structure.
- Documentation now distinguishes recommended operating values from verified prototype performance.
- Corrected RepRapFirmware chamber numbering: the heated chamber is Chamber 0 and the drybox is Chamber 1.

### Hardware files and drawings

- Updated the Valkyrie V2 build guide/BOM.
- Updated the Z idler tower A/B printable parts.
- Updated the Z-probe docking part.
- Updated the Duet cover printable part.
- Updated the LED Front Buddy printable part and added the corresponding LED Buddy drawing.
- Removed duplicate Tool Sensor and Tool Sensor Probe STL files.

### Licensing

- V2.0.0-rc.1 marks the transition of Project Valkyrie to an open-source/open-hardware licensing structure.
- Hardware design files are licensed under CERN-OHL-S-2.0.
- Original Valkyrie firmware, macros, and configuration are licensed under GPL-3.0-or-later.
- Original documentation and project media are licensed under CC-BY-4.0.
- Earlier tagged releases remain under the licence terms under which they were originally published.

## Release highlights

### Frame and enclosure

- Increased frame rigidity using M6 blind joints.
- Relocated upper rear extrusion for improved sealing, panel installation, cable routing, and service access.
- Added centre-rear Z extrusion for additional stiffness and support.
- Revised top-frame structure for top-mounted linear rails.
- Redesigned overhead door that lifts vertically instead of swinging outward.
- New reinforced door brackets, 625ZZ pivot bearings, shoulder bolts, and linked side mechanisms.
- Improved separation between the heated chamber and temperature-sensitive components.

### CoreXY motion system

- External 2.5 A NEMA 17 long-shaft A/B motors with upper shaft supports.
- Drive pulley reduction from 20T to 16T GT2.
- F606ZZ flanged CoreXY idlers.
- High-temperature all-metal MGN12 linear rails.
- Redesigned A/B and Y motion components for improved rigidity, belt alignment, and serviceability.

### Z motion system

- Three independently driven Z motors.
- Z reduction increased from 4:1 to 5:1 using 16T GT2 pulleys.
- New top-mounted Z idler brackets.
- Redesigned Z carriers and belt-clamping interfaces.
- Automatic three-point Z alignment through independent motor control.

### Build platform and calibration

- 350 × 350 × 8 mm cast aluminium 5083 bed plate.
- 330 × 330 mm removable build sheet.
- Three-point Maxwell kinematic mounting system using 10 mm bearing balls.
- Integrated SmCo build-sheet retention magnets.
- Locating pins for repeatable build-sheet positioning.
- Revised bed wiring, strain relief, and integrated thermal fuse.
- Bed-mounted nozzle and Z-offset reference sensor.
- Automatic Z-offset measurement, nozzle-height calibration, and mesh-bed compensation.

### Toolhead

- Water-cooled BTT V2X extruder with 7:1 gearing and 73.5 N (7.5 kgf) rated extrusion force.
- Custom water-cooled Valkyrie hotend rated for nozzle temperatures up to 500 °C.
- Integrated toolplate mounting interface.
- Revised toolhead cable chimney and side cable channel.
- SmCo magnetic probe system and docking station.
- Integrated nozzle-brushing station.

### Thermal management

- Closed-loop toolhead cooling using a P67D pump, reservoir, and external 120 mm radiator.
- 750 W PTC chamber heater positioned at the rear of the build chamber.
- 750 W heated bed used as a secondary chamber heat source.
- 120 CFM chamber-air recirculation fan.
- Nozzle-level chamber-temperature sensing.
- Independent 150 °C thermal switch and firmware heater limits.
- External ROBO part-cooling blower that recirculates heated chamber air through a CPAP hose and toolhead duct.

### Material management

- Integrated drybox with a 300 W PTC heater.
- Drybox heater controlled by RepRapFirmware as Chamber 1.
- Drybox operation up to 80 °C.
- Integrated desiccant container.
- ESP32 monitoring of a DHT22 temperature/humidity sensor and filament load cell.
- 625ZZ-bearing filament carousel.
- External filament buffer with automatic filament loading and unloading.

### Electronics and controls

- Duet 3 6HC controller with all six onboard stepper-driver channels in use.
- No Duet expansion board or CAN-connected toolhead electronics.
- Primary 24 V, 350 W power supply and secondary 12 V supply.
- TS35 DIN-rail mains and 12 V distribution.
- Three 24 V-controlled solid-state relays for the bed, chamber, and drybox heaters.
- GX20 toolhead interfaces positioned outside the heated chamber.
- High-temperature HDC chamber interfaces.
- Three internal 350 mm, 24 V LED strips.
- Primary electronics located outside the heated chamber where practical.

### Firmware and automation

- RepRapFirmware with Duet Web Control.
- Tested Valkyrie V2 `sys`, `macros`, and `filaments` configuration supplied in the repository.
- Input shaping measured and configured on the reference machine.
- Pressure advance support.
- Independent three-motor Z alignment.
- Mesh-bed compensation.
- Automated probe pickup and return.
- Automated nozzle-height and Z-offset measurement.
- Automated nozzle brushing.
- Material-specific filament loading and unloading through Duet Web Control and the external filament buffer.
- Tested print-start, pause/resume, cancel, and normal print-finish workflows.
- Chamber temperature ramping for controlled heat-up.
- Delayed hotend heating until the configured minimum chamber temperature is reached.
- Chamber recirculation-fan tach monitoring with automatic chamber-heater shutdown on fan fault.
- Drybox-fan tach monitoring with automatic drybox-heater shutdown on fan fault.
- Water-pump tach monitoring with automatic print pause and hotend-heater shutdown on cooling fault.
- Pump-fault recovery sequence that verifies cooling before reheating and resuming.
- Firmware temperature limits, heating timeouts, sensor-fault handling, and automatic heater shutdown.

The RC.1 firmware configuration is based on the tested reference machine. Machine-specific values such as input shaping, probe offsets, filament profiles, and other tuning parameters may require adjustment on individual builds.

## Recommended and verified performance

| Performance | Recommended | Verified |
| --- | ---: | ---: |
| Print speed | Up to 500 mm/s | 1,000 mm/s |
| Acceleration | Up to 10,000 mm/s² | 10,000 mm/s² |
| Volumetric flow rate | Material-dependent | 45 mm³/s |
| Chamber temperature | Up to 110 °C | 110 °C sustained for 60 min |
| Drybox temperature | Up to 80 °C | 80 °C |
| Maximum travel speed | Up to 500 mm/s | 1,000 mm/s |
| Chamber heat-up | — | 30 min to 100 °C from 25 °C ambient |

Recommended values are intended as practical operating limits for the Valkyrie V2 reference configuration. Actual print settings depend on material, nozzle size, layer height, toolhead configuration, cooling, firmware tuning, and operating temperature.

Verified values represent results demonstrated on the Valkyrie V2 reference machine.

## Electrical configurations

The standard configuration uses 220-240 VAC and a 10 A mains fuse. An optional 110-120 VAC configuration requires appropriately rated heaters, power supplies, switching devices, wiring, connectors, and circuit protection.

The 110-120 VAC option is not a direct component-for-component conversion of the standard configuration.

## Validation status

The following materials have been validated on the current prototype:

- PLA
- PETG
- ABS
- ASA
- PA and PA-CF
- PC, PC-CF, and PC blend CF
- PPS, PPS-CF, and PPS-GF

PSU, PPSU, PEI (Ultem), and PEKK remain to be verified.

## Documentation

- [Valkyrie V2 Technical Overview v1.1](docs/Valkyrie_V2_Technical_Overview_v1.1.pdf)
- [Valkyrie V2 Firmware Files](Firmware%20Files)
- [Valkyrie Firmware Upgrade Guide](https://docs.google.com/document/d/1ZG3JhbeEWcIs_WRdMjnoR0Aa20OJ4TtpdeJnv2xmSmU/edit?usp=sharing)

The technical overview is not an assembly manual or electrical wiring guide.

## Safety notice

Valkyrie V2 uses mains-voltage heaters, high current, high temperatures, moving machinery, and liquid cooling. Electrical installation and verification must be performed by a qualified person using components appropriate for the configured input voltage and applicable regulations.

## Credits

- **Roy Berntsen** - Project lead, primary mechanical designer, and system integrator.
- **Mark Bridgewater** - Design, electronics, firmware, testing, and documentation.
- **Chris Lombardi** - ESP32 firmware.

Acknowledgements: RepRapFirmware, Duet Web Control, Duet3D, and BIQU.

## Licensing

Beginning with V2.0.0-rc.1:

- hardware design files are licensed under **CERN-OHL-S-2.0**
- original Valkyrie firmware, macros, and configuration are licensed under **GPL-3.0-or-later**
- original documentation and project media are licensed under **CC-BY-4.0**

Earlier tagged releases remain under their original licence terms. See [License.md](License.md) for the complete project licensing structure.

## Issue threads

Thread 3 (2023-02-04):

Configuration.html missing - drybox arduino

aceycv8, 2023-02-04:
Hi Roy and the team,

Thank you for the community project - i've noticed while making the loadcell arduino that the configuration.html is missing from the files list and can't configure the load cell from the page as it's missing,

Are you able to provide the file

thank you

14:26:28.219 -> HEADER[Referer]: http://192.168.0.5/calibration.html
14:26:28.219 -> HEADER[Accept-Encoding]: gzip, deflate
14:26:28.219 -> HEADER[Accept-Language]: en-GB,en-US;q=0.9,en;q=0.8
14:26:28.219 -> File not found
14:26:28.219 -> URL: /configuration.html

Closed 2024-06-17.

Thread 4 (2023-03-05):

offset fan duct design.

FireflyJar, 2023-03-05:
I saw your youtube video 'Fan Duct Design Optimizing by CFD | 3D Printer ToolHead Design | The Triquetra' .
I noticed you did not apply the offset to the Valkyrie project's nozzle, to reduce turbulence.
Would you be applying that offset to the Valkyie someday?

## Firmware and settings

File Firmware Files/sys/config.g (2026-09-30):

; ============================================================================
; Valkyrie V2 / - RepRapFirmware configuration
; Duet 3
; ============================================================================

; ---------------------------------------------------------------------------
; General
; ---------------------------------------------------------------------------
G90                                                               ; use absolute axis coordinates
M83                                                               ; use relative extruder moves
M550 P"Valkyrie_V2"                                               ; set printer name
M669 K1                                                           ; select CoreXY kinematics

; ---------------------------------------------------------------------------
; Network
; ---------------------------------------------------------------------------
M552 S1                                                           ; enable network and acquire address via DHCP
M586 P0 S1                                                        ; enable HTTP
M586 P1 S0                                                        ; disable FTP
M586 P2 S0                                                        ; disable Telnet

; ---------------------------------------------------------------------------
; Drives and motion
; ---------------------------------------------------------------------------
; Drive directions
M569 P0.0 S0                                                      ; X/Y motor A - backwards
M569 P0.1 S0                                                      ; X/Y motor B - backwards
M569 P0.2 S1                                                      ; extruder - forwards
M569 P0.3 S0                                                      ; Z1 - backwards
M569 P0.4 S1                                                      ; Z2 - forwards
M569 P0.5 S0                                                      ; Z3 - backwards

; Drive mapping
M584 X0.0 Y0.1 E0.2 Z0.3:0.4:0.5                                  ; map X, Y, E and three independent Z drives

; Microstepping
M350 X16 Y16 I1                                                   ; X/Y: 16x microstepping with interpolation
M350 Z16 E16 I0                                                   ; Z/E: 16x microstepping without interpolation

; Steps, speeds and acceleration
M92 X100.00 Y100.00 Z400.00 E932.00                               ; steps per mm
M566 X600.00 Y600.00 Z600.00 E600.00                              ; maximum instantaneous speed changes (mm/min)
M203 X90000.00 Y90000.00 Z1500.00 E9000.00                        ; maximum speeds (mm/min)
M201 X10000.00 Y10000.00 Z600.00 E10000.00                        ; accelerations (mm/s^2)

; Motor currents
M906 X1750 Y1750 E900 I30                                         ; X/Y/E motor currents, 30% idle-current factor
M906 Z800 I70                                                     ; Z motor current, 70% idle-current factor
M84 S30                                                           ; motor idle timeout (seconds)

; ---------------------------------------------------------------------------
; Axis limits
; ---------------------------------------------------------------------------
M208 X-3 Y-35 Z-5 S1                                              ; axis minima
M208 X330 Y300 Z275 S0                                            ; axis maxima

; ---------------------------------------------------------------------------
; Endstops and sensorless homing
; ---------------------------------------------------------------------------
M574 X1 S3                                                        ; X homes to low end using sensorless homing
M574 Y1 S3                                                        ; Y homes to low end using sensorless homing
M574 Z2 S4                                                        ; Z homes to high end using sensorless homing

M915 P0.0:0.1 S3 F0 R0                                            ; default X/Y StallGuard settings for sensorless homing
M915 P0.3:0.4:0.5 S4 F0 R0                                        ; default Z1/Z2/Z3 StallGuard settings for sensorless homing

; ---------------------------------------------------------------------------
; Three-point Z geometry
; ---------------------------------------------------------------------------
M671 X0:330:165 Y-8.5:-8.5:321.5 S15                              ; Z lift points: front-left, front-right, rear-center

; ---------------------------------------------------------------------------
; Z probes and bed mesh
; ---------------------------------------------------------------------------
M558 K0 P5 C"^io3.in" H10:5 F1500:300 T30000 A10 S0.025           ; removable bed probe settings
M558 K1 P8 C"^io4.in" H10:5 F1500:300 T30000 A10 S0.025           ; nozzle/tool switch probe settings

G31 K0 P500 X0 Y-19 Z0                                            ; removable probe trigger and offset
G31 K1 P500 X0 Y0 Z0                                              ; nozzle/tool switch trigger and offset

M557 X10:310 Y0:280 S60:56                                        ; bed mesh area and spacing

; ---------------------------------------------------------------------------
; Heaters and temperature sensors
; ---------------------------------------------------------------------------

; Heated bed
M308 S0 P"temp3" Y"thermistor" T100000 B3950 A"Bed T°C"           ; bed temperature sensor
M950 H0 C"out9" T0                                                ; bed heater output mapped to sensor 0
M140 H0                                                           ; map heated bed to heater 0
M143 H0 S150                                                      ; bed heater temperature limit: 150C
M307 H0 R1.177 K0.810:0.000 D4.88 E1.35 S1 B0                     ; bed heater tuning parameters

; Hotend
M308 S1 P"temp0" Y"pt1000" A"Hotend T°C"                          ; hotend PT1000 sensor
M950 H1 C"out1" T1                                                ; hotend heater output mapped to sensor 1
M143 H1 S500                                                      ; hotend temperature limit: 500C
M307 H1 R2.651 K0.222:0.000 D5.73 E1.35 S1.00 B0 V23.2            ; hotend heater tuning parameters

; Heated chamber
M308 S2 P"temp2" Y"thermistor" T100000 B4267 R2200 A"Chamber T°C" ; chamber temperature sensor
M950 H2 C"out8" T2                                                ; chamber heater output mapped to sensor 2
M307 H2 R0.20 K0.25:0.000 D15 E1.35 S1.00 B1                      ; chamber heater tuning parameters 
M570 H2 P60 T15 R5                                                ; chamber heater fault detection parameters
M141 H2 P0                                                        ; map chamber 0 to heater 2
M143 H2 S120                                                      ; chamber heater temperature limit: 120C

; Heated drybox / chamber 1
M308 S3 P"io2.out" Y"dht22" A"dbx Temp[C]"                        ; drybox DHT22 temperature sensor
M308 S4 P"S3.1" Y"dhthumidity" A"drybox Hum[%]"                   ; drybox DHT22 humidity sensor
M950 H3 C"out7" T3                                                ; drybox heater output mapped to sensor 3
M141 H3 P1                                                        ; map chamber 1 to heater 3
M143 H3 S80                                                       ; drybox heater temperature limit: 80C
M307 H3 R0.25 K0.25:0.000 D11 E1.35 S1.00 B0                      ; drybox heater tuning parameters

; ---------------------------------------------------------------------------
; GPIO / power outputs
; ---------------------------------------------------------------------------
M950 P6 C"out0"                                                   ; configure out0 as GPIO output for 12V supply
M42 P6 S1                                                         ; enable 12V supply

; ---------------------------------------------------------------------------
; Fans and water pump
; ---------------------------------------------------------------------------

; CPAP part-cooling fan - 12V
M950 F0 C"io5.out" Q2000                                          ; fan 0 on io5.out
M106 P0 S0 H-1 C"CPAP Fan" B1 L0.1 X0.6                           ; CPAP fan, non-thermostatic

; Chamber circulation fan - 12V
M950 F1 C"!out6+out6.tach" Q25000                                 ; fan 1 with tachometer
M106 P1 S0 H-1 C"Chamber Fan"                                     ; chamber fan, non-thermostatic

; Drybox fan - 12V
M950 F2 C"!out5+out5.tach" Q25000                                 ; fan 2 with tachometer
M106 P2 S0 H-1 C"Drybox Fan"                                      ; drybox fan, non-thermostatic

; CPAP PCB fan - 24V
M950 F3 C"out2" Q25000                                            ; fan 3 on out2
M106 P3 S1 H2 T50 C"PCB Fan"                                      ; PCB fan, non-thermostatic
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

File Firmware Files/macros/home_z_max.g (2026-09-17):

; home all three Z axes independently at Z high end

G91                                  ; use relative positioning

M915 P0.3:0.4:0.5 S4 H400 F0 R0     ; configure Z-axis stall detection for homing
M906 Z500                            ; set Z homing motor current

G1 H1 Z350 F3000                     ; home all three Z motors independently
M400                                 ; wait until homing motion has fully finished

G90                                  ; return to absolute positioning

M906 Z800                            ; restore normal Z motor current
M915 P0.3:0.4:0.5 S20 H500 F0 R1    ; restore normal Z stall detection

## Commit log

2021-09-15 Create BOM Proposal and Options.xlsx
    [BOM Proposal and Options.xlsx]
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2021-09-15 Update BOM Proposal and Options.xlsx
    [BOM Proposal and Options.xlsx]
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2021-11-07 Update Valkyrie Base Frame BOM 00.xlsx
    [Valkyrie Base Frame BOM 00.xlsx]
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2022-01-02 Create Top Plate Mosquito with conectors concept 1 v1.f3z
    [Top Plate Mosquito with conectors concept 1 v1.f3z]
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2022-01-04 Updated Carousel Files
    Latest version using MR115 bearings, which will change. Files includes most hardware, excluding the tension spring and MR115 bearings. Final minimum and maximum internal spool diameter not currently 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
    [Horizontal Spool Holder with AutoTightener-v5.FCStd]
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2022-03-13 Latest drybox design files and new directory structure
    [BOM.xlsx, Chrisousel.FCStd, Chrisousel.step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]
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2022-03-19 updated retainer to have a rounded inner corner
    [Desiccant Box-Retainer - Magnets and Screws (Meshed).stl]
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2022-04-19 RC-08 update
    New angle for the Z lifters due to the new constant for defining the center of the maxvell for a trouble free scalable design
    [Z Carrier A_1x.stl, Z Carrier B_1x.stl, Z Carrier C_1x.stl]
2022-04-20 Bearing pin updated to 8mm
    It was undersized
    [Bearing Pin_3x.stl, Heater Cover-Fan Shroud_1x.stl]
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2022-04-26 ab motor bracket.
    more tolerance for the ab motors not so tight
    [AB Motor Bracket_1x.stl]
2022-04-30 Print file update
    Z gear covers and 3030 AB bracket
    [3030 AB Motor Bracket_1x.stl, Z Gear Chimney A Cover_1x.stl, Z Gear Chimney B Cover_1x.stl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]
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2022-05-03 Add back missing files
    [Center Pin Jig_1x.stl, Load Cell Drill Jig_1x.stl, Round Jaw_3x.stl]
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2022-05-14 Changes thermal fuse
    Changed from 135C to 160C for 150 bed temps
    [Valkyrie BOM RC-08.xlsx]
2022-05-14 thermal fuse update
    revoked update to resistor type. Added back screw type. Note on temps selection in bom
    [Valkyrie BOM RC-08.xlsx]
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2022-08-03 BOM update
    Changed number of brackets from 42 to 40. Now only 4 packs of 10, not 5
    [Valkyrie BOM v1.0.0.xlsx]
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2022-08-05 Update Valkyrie Duet 3 6HC Connection Table.xlsx
    added chamber temp
    [Valkyrie Duet 3 6HC Connection Table.xlsx]
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2022-08-11 moved some documents
    removed some personal resource docs
    [1226T14_Washdown Weather-Resistant Breather Vent.STEP, 2815K188_Compression Fitting for Copper Tubing.STEP, 5357K188_Aluminum Barbed Hose Fitting.STEP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]
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2022-09-06 BOM update
    REmoved BL-Touch from BOM. Now using the printed Unclid magnetic switch
    [Valkyrie BOM v1.0.0.xlsx]
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2022-09-10 Added purge bucket to the options file folder
    [Purge Bucket.stl]
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2022-09-14 BOM update
    Changed the drybox describtion to sunon
    [Valkyrie BOM v1.0.0.xlsx]
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2023-06-24 Create ROS Buddy.stl
    Throughput for the run out sensor
    [ROS Buddy.stl]
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2023-10-30 update to new toolhead
    for the H2 lite extruder
    [A Idler Bracket Front_1x.stl, A Idler Bracket Rear_1x.stl, A Idler Tension Tower_1x.stl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]
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2023-11-11 Magnet delete
    Removed magnets in the Z carriers
    [Valkyrie BOM v1.1.0.xlsx, Z A-Carrier_1x.stl, Z B-Carrier_1x.stl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]
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2024-05-14 AB motor cover updated
    Removed holes for tensioning. Pull the cover to do this rather
    [AB Rear Motor Cover_1x.stl]
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2024-06-17 Updated Z lifters
    Changed the M3 holes to fit M3x08
    [Z A-Carrier_1x.stl, Z B-Carrier_1x.stl]
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2024-07-26 aluminum tube replace carbon
    [Valkyrie BOM v1.1.0.xlsx]
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2026-01-08 frame and full bom update
    updated to accommodate for M6 leg base
    [Valkyrie V2 HT100 BOM Beta.xlsx]
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2026-05-14 All Z parts updated
    All chamber parts are being beta tested these days. The gearboxes has not been tested yet
    [AB Idler Tension Fork_2x.stl, V2 Idler Tension Fork AB_2x.stl, V2 Tool Sensor Housing_1x.stl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]
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2026-05-25 V2 tool plate
    Fixed suppportblocl
    [V2 Tool Plate _1x.stl, V2 Tool Plate_1x.stl]
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2026-06-15 v2 tool carrier
    change to the belt entrance for easier install
    [V2 Tool Carrier_1x.stl, Valkyrie V2 HT100 Build Guide Beta.xlsx]
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2026-07-26 v2
    increased thickness of the extruder cable channel and chimney to allow for the M3x08 SH DIN 912 hardware fitment
    [Chamber Heater Data.xlsx, V2 Extruder Cable Channel_1x.stl, V2 Extruder Cable Chimney_1x.stl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]
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2026-08-04 Prepare Valkyrie V2 beta release
    Prepare Valkyrie V2 beta release
    [350 build plate cut pattern.dxf, A Idler Bracket Front_1x.stl, A Idler Bracket Rear_1x.stl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]
2026-08-04 V2 - BOM PDF update
    fixed broken links
    [Valkyrie V2 Build Guide.xlsx]
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2026-08-26 v2 gx20 update
    added place for the quick release water conenctors
    [V205 Extruder Cable Chimney_1x.stl, V205 GX20 Buddy_1x.stl, V205 GX20 Cover_1x.stl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]
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2026-09-11 V2 cPAP bracket
    longer so it dont sqeeze the fan
    [V205 CPAP ROBO Fan Bracket_1x.stl, Valkyrie V2 Build Guide.xlsx]
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2026-09-17 renamed customs to temp
    just a temporary folder
    [rgb.g, trigger4.g]
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2026-09-26 V2 Beta 2 update
    Small change to the front Z idler towers. Added path to LED front Top wiring
    [V205 Z Idler Tower A_1x.stl, V205 Z Idler Tower B_1x.stl, Valkyrie V2 Build Guide.xlsx]
2026-09-26 v2 firmware update
    changes to start.g - start.g and end.g are now placed in the macros folder.
    [bed.g, cancel.g, chamber_ramp.g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]
2026-09-26 v2 firmware
    moved start.g and end.g to sub folder
    [end.g, start.g]
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2026-09-27 v2 firmware
    added safety features to all heaters and fans
    [cancel.g, daemon.g, globals.g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]
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
